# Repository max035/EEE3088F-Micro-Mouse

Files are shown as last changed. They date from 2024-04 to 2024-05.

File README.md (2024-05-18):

# EEE3088F-Micro-Mouse

This project is made up of five modulues. Namely the mother board, the processor, power and sensing. We will be focusing on power and sensing.

## Sensing Subsystem

The sensing subsystem is a crucial component of the micro-mouse project, responsible for detecting walls and enabling the robot to navigate the maze effectively. This subsystem consists of three main components:

1. Emitter-Receiver (ER) Sensor Subsystem
2. Power Saving Mechanism
3. Output and Level Shifting

### Emitter-Receiver (ER) Sensor Subsystem

The ER sensor subsystem includes three separate ER circuits for left, front, and right wall detection. Each circuit utilizes a TSAL4400 IR emitting diode and an SFH203 photodiode. The emitter circuit is designed to provide the optimal current of 100mA to the IR emitting diode, while the receiver circuit uses a 100kΩ resistor in series with the photodiode for sensitive output.

### Power Saving Mechanism

To reduce power consumption, the sensing subsystem employs Pulse Width Modulation (PWM) to control the duty cycle of the ER circuits. PWM allows the ER sensors to operate for a shorter time while still functioning as intended, resulting in significant power savings compared to continuous operation.

### Output and Level Shifting

Initially, the analog output signals from the ER sensors were intended to be converted to digital levels using an NPN and PNP transistor-based level shifter. However, during testing, it was determined that connecting the analog outputs directly to the ADC pins of the microcontroller (PA4, PA5, PA6) provided a more adaptable and robust solution for handling variations in ambient light conditions.

### PCB Design

The sensing subsystem PCB has been designed to fit within the available space on the micro-mouse chassis, with a width less than 70mm and a length between 6mm and 50mm. The PCB includes strategically placed jumpers for debugging and test points for probing, facilitating easy troubleshooting and modification. The PCB connects to the motherboard via a 2x14 pin header.

### Acceptance Testing

The sensing subsystem has undergone rigorous acceptance testing to ensure its functionality, reliability, and compatibility with the micro-mouse platform. The testing procedures covered the following aspects:

1. Functionality test of the ER subsystems (AT-01)
2. Consistency test of the sensing subsystem's output voltage (AT-02)
3. Functionality test of the sensing subsystem software (AT-03)
4. Power consumption test of the sensing subsystem (AT-04)
5. Physical compatibility test (AT-05)

The results of the acceptance tests demonstrated the effectiveness of the design decisions and modifications made throughout the project, ensuring that the sensing subsystem meets the project's requirements and specifications.

For more detailed information on the sensing subsystem design, testing, and results, please refer to the [project report](/Sensing%20Subsystem/Write%20Up/EEE3088F_final_report.pdf).

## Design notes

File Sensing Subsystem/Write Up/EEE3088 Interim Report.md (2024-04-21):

# Introduction

## Problem Description
The micro-mouse project aims to design and construct subassemblies for a simplified maze-solving robot. The project is divided into four modules: processor, motherboard, sensing, and power. Working in pairs, each student is responsible for designing either the sensing or power subsystem. The objective is to create a functional micro-mouse that navigates a maze while adhering to a strict budget and meeting the specified requirements for each subsystem. The sensing subsystem, which is the focus of this report, plays a crucial role in detecting obstacles and walls, enabling the micro-mouse to navigate the maze effectively.

## Scope and limitations
The scope of this project is limited to the design and implementation of the sensing subsystem for the micro-mouse robot. The subsystem will include obstacle detection sensors, power-saving features, and the necessary code to interface with the processor board. However, the design will not cover the integration of the sensing subsystem with the other modules or the overall navigation algorithm for the micro-mouse.

The project's limitations include the strict budget constraints, which may impact component selection and design choices. Additionally, the sensing subsystem's performance may be affected by factors such as sensor accuracy, ambient light conditions, and battery life. Testing and development may also be limited by the availability of resources and time constraints.

# Requirements Analysis

## Requirements

| ID | Requirement |
| ----- | --- |
| UR-01 | The sensing subsystem should detect walls in front and on the sides of the micro-mouse. |
| UR-02 | The sensing subsystem should consume minimal power to maximize battery life. |
| UR-03 | The sensing subsystem should be reliable and consistently detect walls. |
| FR-01 | The sensing subsystem must include sensors capable of detecting walls within a suitable range for maze navigation. |
| FR-02 | The sensing subsystem must use PWM to control the sensor power, reducing overall power consumption. |
| FR-03 | The sensing subsystem must communicate wall detection data to the processor board through the state of the LEDs. |
| FR-04 | The sensing subsystem must fit within the available space on the micro-mouse chassis and connect to the 2x14 pin header on the motherboard. |
| FR-05 | The sensing subsystem must include software that processes sensor data and determines the presence of walls on the left, right, and front of the micro-mouse. |

## Specifications

| ID | Specification |
| --- | --- |
| SPEC-01 | The sensing subsystem shall detect walls within a range suitable for the micro-mouse maze navigation. |
| SPEC-02 | The sensing subsystem shall use a PWM duty cycle that reduces power consumption by at least 50% compared to continuous operation. |
| SPEC-03 | The sensing subsystem shall use the processor board's LEDs to indicate the presence of walls, with one LED each for the left, right, and front walls. |
| SPEC-04 | The sensing subsystem PCB shall fit within the available space on the micro-mouse chassis and connect to the 2x14 pin header on the motherboard. |
| SPEC-05 | The sensing subsystem software shall process sensor data and determine the presence of walls. |

## Testing Procedures

| ID | Test Procedure | Test Method | Pass/Fail Criteria |
| --- | --- | --- | --- |
| TEST-01 | Verify that the sensing subsystem detects walls within the suitable range for maze navigation. | Place the micro-mouse in a controlled environment with walls at various distances and orientations. Monitor the sensor output and LED indicators. | The sensing subsystem should consistently detect walls within the suitable range, and the corresponding LEDs should illuminate. |
| TEST-02 | Verify that the sensing subsystem reduces power consumption by at least 50% using PWM compared to continuous operation. | Measure the sensing subsystem's power consumption with PWM enabled and disabled. Compare the results. | The power consumption with PWM enabled should be at least 50% lower than with PWM disabled. |
| TEST-03 | Verify that the sensing subsystem communicates wall detection data to the processor board through the state of the LEDs. | Place the micro-mouse in a controlled environment with walls on the left, right, and front. Observe the LED indicators. | The corresponding LEDs should illuminate when walls are detected on the left, right, or front of the micro-mouse, effectively communicating the wall detection data to the processor board. |
| TEST-04 | Verify that the sensing subsystem PCB fits within the available space on the micro-mouse chassis and connects to the 2x14 pin header on the motherboard. | Assemble the sensing subsystem PCB onto the micro-mouse chassis and check for proper fit and connection. | The sensing subsystem PCB should fit within the available space without interference and securely connect to the 2x14 pin header. |
| TEST-05 | Verify that the sensing subsystem software processes sensor data and determines the presence of walls on the left, right, and front of the micro-mouse.  | Place the micro-mouse in a controlled environment with walls on the left, right, and front. Monitor the sensor data and wall presence indicators. | The sensing subsystem software should accurately determine the presence of walls based on the sensor data. |

## Traceability Analysis

| FR ID | Specification ID(s) | Testing Procedure ID(s) |
| ----- | --- | --- |
| FR-01 | SPEC-01 | TEST-01 |
| FR-02 | SPEC-02 | TEST-02 |
| FR-03 | SPEC-03 | TEST-03 |
| FR-04 | SPEC-04 | TEST-04 |
| FR-05 | SPEC-05 | TEST-05 |

FR-01 is satisfied by SPEC-01, which states that the sensing subsystem shall detect walls within a range suitable for micro-mouse maze navigation. This requirement is verified by TEST-01, where the micro-mouse is placed in a controlled environment with walls at various distances and orientations to ensure that the sensing subsystem consistently detects walls within the suitable range.

FR-02 is satisfied by SPEC-02, which states that the sensing subsystem shall use a PWM duty cycle that reduces power consumption by at least 50% compared to continuous operation. This requirement is verified by TEST-02, where the power consumption of the sensing subsystem is measured with PWM enabled and disabled, and the results are compared to ensure that the power consumption with PWM enabled is at least 50% lower than with PWM disabled.

FR-03 is satisfied by SPEC-03, which states that the sensing subsystem shall use the processor board's LEDs to indicate the presence of walls, with one LED each for the left, right, and front walls. This requirement is verified by TEST-03, where the micro-mouse is placed in a controlled environment with walls on the left, right, and front, and the LED indicators are observed to ensure that the corresponding LEDs illuminate when walls are detected, effectively communicating the wall detection data to the processor board.

FR-04 is satisfied by SPEC-04, which states that the sensing subsystem PCB shall fit within the available space on the micro-mouse chassis and connect to the 2x14 pin header on the motherboard. This requirement is verified by TEST-04, where the sensing subsystem PCB is assembled onto the micro-mouse chassis and checked for proper fit and connection to ensure that it fits within the available space without interference and securely connects to the 2x14 pin header.

FR-05 is satisfied by SPEC-05, which states that the sensing subsystem software shall process sensor data and determine the presence of walls. This requirement is verified by TEST-05, where the micro-mouse is placed in a controlled environment with walls on the left, right, and front, and the sensor data and wall presence indicators are monitored to ensure that the sensing subsystem software accurately determines the presence of walls based on the sensor data.

# Design Decisions

## Component Selection

### Sensor Types Considered

| Sensor Type | Description | Pros | Cons |
| --- | --- | --- | --- |
| QRD1114 | Reflective object sensor with integrated infrared emitting diode and NPN silicon photodarlington | - Compact all-in-one package<br>- Ideal for non-contact detection of reflective materials<br>- Can detect objects in close proximity or differentiate between black and white surfaces | - Did not work well for long distances<br>- Not used in the breadboard assignment |
| SFH205 + TSAL6100 | Photodiode (SFH205) paired with high-power infrared emitting diode (TSAL6100) | - Proved to work well for longer distances<br>- SFH205 has a short switching time and is suitable for 950 nm wavelength applications<br>- TSAL6100 has a peak wavelength of 940 nm, making it a good match for the SFH205 | - Sensitive to environmental lighting<br>- Potentially higher complexity and cost due to multiple components |

**Selected Sensor: SFH205 + TSAL6100**  
**Reasons:**  
- Better performance at longer distances  
- Prior experience with these components during the breadboard assignment  

## Voltage Regulation and Level Shifting

### Circuit Type Considered

| Circuit Type | Pros | Cons |
| --- | --- | --- |
| Voltage Regulator | - Possibly more stable and reliable<br>- Typically used for stepping down voltages, not suitable for stepping up small, fluctuating voltages<br>- Higher power consumption | - More expensive than transistor-based solutions |
| MOSFET-based Level Shifter | - Less complex than transistor-based solution<br>- More precise | - Less familiarity with MOSFETs<br>- Possibly higher power consumption |
| Transistor-based Level Shifter (NPN + PNP) | - Readily available components<br>- Inexpensive<br>- Simulated and tested, proving to be sufficient for the application | - Slightly more complex than MOSFET-based solution |

**Selected Circuit: Transistor-based Level Shifter (NPN + PNP)**  
**Reasons:**  
- Familiarity with transistors  
- Readily available components in case of damage  
- Cost-effective solution  

## Sensing Subsystem Subcircuits

1. Emitting Circuit
2. Receiver Circuit
3. Level Switching/Shifting Circuit

## Interfacing

- 2x14 connector for interfacing with the main system

# My comment:
Mistakes I made in the EEE3088 Project:
+Used a GPIO pin do drive current into my circuit instead of as battery: A GPIO pin in an STM32 does not supply a lot of current(25mA maximum), it should instead be used as reference(switch). I should have connected the GPIO pin to a MOSFET that is connected to the BATT pin so 
it can drive the circuit instead. This error will result in the insufficient current driving the circuit.
+Insufficient use of Jumpers and test points: Now that I am noticing all the mistakes I have made, having more strategically placed jumpers and test points would have help me on my journey to fix the PCB.
+Small track width: I used a small track width of 0.2mm, this is not advisable for high currents(do research)
+Approach to design: I approached this project from the wrong prospective. I should have built based on available components in JLPCB, Instead,
I build the circuit with components I wanted and them realized that the components were not available/feasible, making me work around my design, downgrading my design, and making compromises late in the design process
that affected the quality of the final product. Instead if I had a scope of available components and worked from there I would have made less design mistakes and compromises.
(The reason I took my initial approach is because I had already built my initial design with everything working(well suited components selected) so I thought it would just be a matter of building from there. 
TLDR: should have designed with component availability in mind earlier on.
+Lack of understanding of components specifications: I should have also designed with the ratings of the components in mind, as in:
The GPIO pin is basically rated at 3V3 25mA, so I would never handed more that 25mA demand, which is a problem because the sensing portion of my circuit requires a current well over 25mA, for instance, the IR emitter
requires like 100mA to emit to far distances
+Going over design. Double checking everything: I made some silly mistakes in this design like forgetting to correctly assign certain important Netlabels making some of my routing incorrect.
A check of Netlabels should be done to ensure everything is going to the right place.
+Willness to go outside my comfort zone: Had I had the courage I would have used unfamiliar components that would clearly benefited me, e.g. MOSFET, different photodiode(components in general) from the one I used in the Breadboard Assignment,
etc...
+For the emitter circuit, instead of using a low resistor value to get the desired current, I would use a npn as a current source to drive it
+I choose to go for a switching circuit where once a certain voltage is reached based on distance, the circuit would indicated that by turning on an led, this would be directly via a level shifter.
+Another way I could have done this is via Analogue to Digital Conversion, where I would have taken the voltage read by the circuit and coded it to determine when the voltage is on instead via ADC. It could have made a better design in 2 ways. 1. Less components used as no need for level shifting circuit. 2. Possibly more precise way to capture signal received by the receiver circuit for use achieving requirement via ADC. It might have also been more precise maybe, I'm not sure.
+Seem it is advisable to use ground plane on the top and bottom of the PCB. I did not do this, it seems to not be too much of a train smash. But maybe the configuration of the ADC would have been a bit complex

+Another circuit I did consider was a transimpedance amplifier for better current to voltage "conversion". But didn't end up doing with it because of the potential expense in power and cost(given the limited budget) of adding an op amp

# My design desisions
## Emitter Reciever Subsystem
### Emitter Circuit
- From the breadboard assignment, the TSAL6100 was perfect component for IR Sensor applications.
- With enough current though, $I_{f}=100mA$ is worked well to reach

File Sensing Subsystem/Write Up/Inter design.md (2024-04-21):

# Chapter 1: Introduction

## 1.1 Problem Description

The micro-mouse project aims to design and construct subassemblies for a simplified maze-solving robot. The project is divided into four modules: processor, motherboard, sensing, and power. Working in pairs, each student is responsible for designing either the sensing or power subsystem. The objective is to create a functional micro-mouse that navigates a maze while adhering to a strict budget and meeting the specified requirements for each subsystem. The sensing subsystem, which is the focus of this report, plays a crucial role in detecting obstacles and walls, enabling the micro-mouse to navigate the maze effectively.

## 1.2 Scope and Limitations

The scope of this project is limited to the design and implementation of the sensing subsystem for the micro-mouse robot. The subsystem will include obstacle detection sensors, power-saving features, and the necessary code to interface with the processor board. The design will cover the integration of the sensing subsystem with the other modules and the overall navigation algorithm for the micro-mouse, which will be discussed in the System Integration and Interfacing section.

The project's limitations include the strict budget constraints, which may impact component selection and design choices. Additionally, the sensing subsystem's performance may be affected by factors such as sensor accuracy, ambient light conditions, and battery life. Testing and development may also be limited by the availability of resources and time constraints.

## 1.3 GitHub Link

https://github.com/username/micromouse-sensing-subsystem

# Chapter 2: Requirements Analysis

## 2.1 Requirements

Table 2.1: User and functional requirements of the sensing subsystem.

| Requirement ID | Description |
| --- | --- |
| UR-01 | The sensing subsystem should detect walls in front and on the sides of the micro-mouse. |
| UR-02 | The sensing subsystem should consume minimal power to maximize battery life. |
| UR-03 | The sensing subsystem should be reliable and consistently detect walls. |
| FR-01 | The sensing subsystem must include sensors capable of detecting walls within a suitable range for maze navigation. |
| FR-02 | The sensing subsystem must use a power-saving mechanism to reduce overall power consumption. |
| FR-03 | The sensing subsystem must communicate wall detection data to the processor board through the state of the LEDs. |
| FR-04 | The sensing subsystem must fit within the available space on the micro-mouse chassis and connect to the 2x14 pin header on the motherboard. |
| FR-05 | The sensing subsystem must include software that processes sensor data and determines the presence of walls on the left, right, and front of the micro-mouse. |

## 2.2 Specifications

Table 2.2: Specifications of the sensing subsystem derived from the requirements in Table 2.1.

| Specification ID | Description |
| --- | --- |
| SPEC-01 | The sensing subsystem shall detect walls within a range suitable for the micro-mouse maze navigation, with a block in the maze being 200mm x 200mm. |
| SPEC-02 | The sensing subsystem shall use a power-saving mechanism that significantly reduces power consumption compared to continuous operation. |
| SPEC-03 | The sensing subsystem shall use the processor board's LEDs to indicate the presence of walls, with one LED each for the left, right, and front walls. |
| SPEC-04 | The sensing subsystem PCB shall fit within the available space on the micro-mouse chassis and connect to the 2x14 pin header on the motherboard. |
| SPEC-05 | The sensing subsystem software shall process sensor data and determine the presence of walls. |

## 2.3 Testing Procedures

Table 2.3: Summary of the testing procedures detailed in Chapter 4.

| Acceptance Test ID | Description |
| --- | --- |
| AT-01 | Verify that the sensing subsystem detects walls within the suitable range for maze navigation. |
| AT-02 | Verify that the sensing subsystem reduces power consumption using a power-saving mechanism compared to continuous operation. |
| AT-03 | Verify that the sensing sub  system communicates wall detection data to the processor board through the state of the LEDs. |
| AT-04 | Verify that the sensing subsystem PCB fits within the available space on the micro-mouse chassis and connects to the 2x14 pin header on the motherboard. |
| AT-05 | Verify that the sensing subsystem software processes sensor data and determines the presence of walls on the left, right, and front of the micro-mouse.  |

## 2.4 Traceability Analysis

Table 2.4: Requirements Traceability Matrix

| # | Requirements | Specifications | Acceptance Test |
| --- | --- | --- | --- |
| 1 | UR-01 | SPEC-01 | AT-01 |
| 2 | UR-02 | SPEC-02 | AT-02 |
| 3 | UR-03 | SPEC-03, SPEC-05 | AT-03, AT-05 |
| 4 | FR-01 | SPEC-01 | AT-01 |
| 5 | FR-02 | SPEC-02 | AT-02 |
| 6 | FR-03 | SPEC-03 | AT-03 |
| 7 | FR-04 | SPEC-04 | AT-04 |
| 8 | FR-05 | SPEC-05 | AT-05 |

### 2.4.1 Traceability Analysis 1

UR-01 is satisfied by SPEC-01, which states that the sensing subsystem shall detect walls within a range suitable for micro-mouse maze navigation, with a block in the maze being 200mm x 200mm. This requirement is verified by AT-01, where the micro-mouse is placed in a controlled environment with walls at various distances and orientations to ensure that the sensing subsystem consistently detects walls within the suitable range.

### 2.4.2 Traceability Analysis 2

UR-02 is satisfied by SPEC-02, which states that the sensing subsystem shall use a power-saving mechanism that significantly reduces power consumption compared to continuous operation. This requirement is verified by AT-02, where the power consumption of the sensing subsystem is measured with the power-saving mechanism enabled and disabled, and the results are compared to ensure that the power consumption with the power-saving mechanism enabled is significantly lower than with it disabled.

### 2.4.3 Traceability Analysis 3

UR-03 is satisfied by SPEC-03 and SPEC-05. SPEC-03 states that the sensing subsystem shall use the processor board's LEDs to indicate the presence of walls, with one LED each for the left, right, and front walls. SPEC-05 states that the sensing subsystem software shall process sensor data and determine the presence of walls. These requirements are verified by AT-03 and AT-05, respectively. AT-03 checks if the corresponding LEDs illuminate when walls are detected, effectively communicating the wall detection data to the processor board. AT-05 verifies that the sensing subsystem software accurately determines the presence of walls based on the sensor data.

### 2.4.4 Traceability Analysis 4

FR-01 is satisfied by SPEC-01, which states that the sensing subsystem shall detect walls within a range suitable for the micro-mouse maze navigation, with a block in the maze being 200mm x 200mm. This requirement is verified by AT-01, where the micro-mouse is placed in a controlled environment with walls at various distances and orientations to ensure that the sensing subsystem consistently detects walls within the suitable range.

### 2.4.5 Traceability Analysis 5

FR-02 is satisfied by SPEC-02, which states that the sensing subsystem shall use a power-saving mechanism that significantly reduces power consumption compared to continuous operation. This requirement is verified by AT-02, where the power consumption of the sensing subsystem is measured with the power-saving mechanism enabled and disabled, and the results are compared to ensure that the power consumption with the power-saving mechanism enabled is significantly lower than with it disabled.

### 2.4.6 Traceability Analysis 6

FR-03 is satisfied by SPEC-03, which states that the sensing subsystem shall use the processor board's LEDs to indicate the presence of walls, with one LED each for the left, right, and front walls. This requirement is verified by AT-03, where the micro-mouse is placed in a controlled environment with walls on the left, right, and front, and the LED indicators are observed to ensure that the corresponding LEDs illuminate when walls are detected, effectively communicating the wall detection data to the processor board.

### 2.4.7 Traceability Analysis 7

FR-04 is satisfied by SPEC-04, which states that the sensing subsystem PCB shall fit within the available space on the micro-mouse chassis and connect to the 2x14 pin header on the motherboard. This requirement is verified by AT-04, where the sensing subsystem PCB is assembled onto the micro-mouse chassis and checked for proper fit and connection to ensure that it fits within the available space without interference and securely connects to the 2x14 pin header.

### 2.4.8 Traceability Analysis 8

FR-05 is satisfied by SPEC-05, which states that the sensing subsystem software shall process sensor data and determine the presence of walls. This requirement is verified by AT-05, where the micro-mouse is placed in a controlled environment with walls on the left, right, and front, and the sensor data and wall presence indicators are monitored to ensure that the sensing subsystem software accurately determines the presence of walls based on the sensor data.

# Chapter 3: Subsystem Design

## 3.1 Design Decisions

### 3.1.1 Final Design

![[Screenshot 2024-04-18 200731.png]]

![[Screenshot 2024-04-17 222953.png]]

![[Screenshot 2024-04-17 223008.png]]

![[Screenshot 2024-04-17 223117.png]]

![[Screenshot 2024-04-17 204755.png]]

---
## 3.1 Design Decisions

### 3.1.1 Component Selection

| Component | Options Considered | Pros | Cons | Final Selection |
| --- | --- | --- | --- | --- |
| IR Emitting Diode | - TSAL6100<br>- TSAL6200<br>- TSAL4400 | - Work well at 100mA current<br>- Suitable for desired sensing distance<br>- Low power consumption <br> - Familiarity with component TSAL6100 due to breadboard assignment | - Limited stock availability on JLCPCB for TSAL6100 and TSAL6200 <br>- TSAL4400 is made to sense IR light from it top, unlike the side body for the TSAL6100 and TSAL6200 | TSAL4400 <br>- Reason: Component availability |
| Photodiode | - SFH205FA<br>- SFH203PFA | - Suitable for side-facing detection<br>- Works well with 100kΩ resistor in reverse bias configuration <br> - Familiarity with component SFH205FA due to breadboard assignment | - Limited stock availability on JLCPCB for SFH205FA <br>- SFH203 is made to sense IR light from it top, unlike the side body for the SFH205 | SFH203PFA <br>- Reason: Component availability |
| Phototransistor | - QRD113<br>- QRD114 | - Suitable for short-distance applications <br>- Good stock availability on JLCPCB | - Not suitable for long-distance sensing required in this project | Not selected <br>- Reason: Component availability |

The TSAL4400 and SFH203PFA were chosen primarily due to their availability on JLCPCB, despite the limitations compared to the TSAL6100 and SFH205FA. The IR emitting diode and photodiode combination was preferred over phototransistors (QRD113 and QRD114) because of their proven performance in long-distance sensing during the breadboard assignment.

### 3.1.2 Power Saving Mechanism

Pulse Width Modulation (PWM) was selected to control the power supplied to the ER sensors, effectively reducing the overall power consumption of the sensing subsystem. This allows the ER sensors to operate for a shorter time while still functioning as intended, as long as the duty cycle is appropriately configured.

However, it is important to note that sourcing current directly from the GPIO pin may not be the best approach. A better solution would be to use a MOSFET switching circuit with PWM as the switch, and the circuit connected to the 3.7V battery for power. This would ensure that the GPIO pin is not overloaded and the ER sensors receive adequate current.

The appropriate duty cycle will be determined during testing when the PCB is received.

### 3.1.3 Output and Level Shifting

The analog output signals from the ER sensors need to be converted into a format that the processor can use to detect the presence of a wall and control an LED indicator. While an ADC could directly convert the analog signals for processing, a level shifting circuit offers a simpler solution. A level shifter translates signals between different voltage or logic levels, allowing the analog voltages from the ER sensors to be converted to digital levels compatible with the processor. This approach simplifies the interfacing between the sensing subsystem and the processor, enabling efficient wall detection and LED control without the need for a complex ADC solution.

| Design Decision | Options Considered | Pros | Cons | Final Selection |
| --- | --- | --- | --- | --- |
| Level Shifting  | 1. NPN and PNP transistor-based level shifter<br>2. MOSFET-based level shifter | 1. Familiarity with transistors<br>- Easily sourced from White Lab if needed<br>- Less expensive than MOSFETs<br>2. No current drawn at the gate from ER sensor output<br>- Requires only one MOSFET | 1. Requires two transistors<br>2. More expensive than transistors | NPN and PNP transistor-based level shifter |

To ensure that the level-shifting circuit would work reliably with the ER sensor outputs, simulations were conducted using LT Spice. The input into the level shifter was varied, confirming that voltages less than 0.7V resulted in approximately 0V output, while voltages greater than 0.7V resulted in approximately 3.3V output. Additionally, the ER sensor's functionality had already been verified during the breadboard assignment.

### 3.1.4 PCB Layout and Routing

| Design Decision | Description | Rationale |
| --- | --- | --- |
| Component Placement | - ER sensors placed to avoid obstruction by wheels<br>- PCB extended forward to accommodate ER sensors | - Ensure unobstructed wall detection on left and right sides<br>- Maintain compact PCB size while allowing proper ER sensor functionality |
| Routing | - Tracks placed and routed for all components<br>- Ground plane not included on top and bottom layers (mistake) | - Ensure proper connectivity between components<br>- (Mistake) Thought tracks and routing would be sufficient without ground planes |

In hindsight, not including a ground plane on both the front and back of the board was a mistake. Ground planes offer several benefits, such as reducing noise and EMI, enhancing power delivery, facilitating improved thermal management, and simplifying routing.

### 3.1.5 Unique Designs 
#### 1. Unique Design Decision 1: Analog to Digital Logic Converter

Instead of sending the analog output signal from the ER sensor directly to the processor for processing by the ADC, a level shifter was implemented to convert the analog signal to digital logic levels. The level shifter acts as an analog to digital logic converter, where voltages less than 0.7V produce a 0V output, and voltages greater than 0.7V produce a 3.3V output. This approach simplifies the interfacing between the sensing subsystem and the processor, as the processor can directly use the digital logic levels for wall detection.

#### 2. Unique Design Decision 2: PCB Shape Modification for Sensor Placement

The provided template for the sensing subsystem PCB design posed a challenge, as the left and right sensors would be obstructed by the wheels of the micromouse. To overcome this issue, the decision was made to extend the PCB forward just enough to ensure that the sensors were not obstructed. This modification required careful consideration to maintain the micromouse's ability to fit within one block of the maze and to minimize the impact on the center of gravity.

An alternative solution considered was to rotate the board to still obtain left and right wall data while avoiding wheel obstruction. However, this approach was deemed potentially more complicated than simply extending the board.

#### 3. Unique Design Decision 3: Jumper for Potentiometer Calibration

A jumper was included in the design to allow for the connection of a potentiometer. The potentiometer can be used to fine-tune the output of the ER sensor if calibration is needed. Although the potentiometer was not populated to reduce costs, it can be easily sourced from the White Lab if required. This design decision provides flexibility in adjusting the sensing subsystem's performance without the need for significant hardware modifications.

---

The final solution for the sensing subsystem consists of three main components:

1. Emitter-Receiver (ER) Sensor Subsystem: Three separate ER circuits for left, front, and right wall detection, each using a TSAL4400 IR emitting diode and an SFH203 photodiode.
2. Power Saving Mechanism: Pulse Width Modulation (PWM) is used to reduce power consumption by controlling the duty cycle of the ER circuits.
3. Output and Level Shifting: An NPN and PNP transistor-based level shifter is used to convert the output signals from the ER circuits to digital levels suitable for the GPIO pins of the STM32 processor.

## 3.2 Failure Management

Table 3.1: Failure management processes and their rationale.

| Failure Management Process | Description | Rationale |
| --- | --- | --- |
| Jumpers for debugging | Jumpers were placed at strategic locations on the PCB. | Jumpers allow for easy debugging and troubleshooting by providing access points to test and isolate different parts of the circuit. They could also be used as a means to place other components onto the PCB if needed. |
| Test points for probing | Test points were included at critical nodes in the circuit. | Test points facilitate probing and measuring signals at various stages of the circuit, aiding in diagnosing issues and verifying correct operation. |
| Potentiometer jumper option | A jumper option was included to allow the connection of a potentiometer in parallel with the 10kΩ resistor. | The potentiometer provides adjustability for fine-tuning the circuit if needed. It was not populated to reduce costs but can be sourced from the White Lab if required. |
| Overcurrent protection | Current-limiting resistors were used in series with the emitter and other sensitive components. | Current-limiting resistors help prevent damage to components due to excessive current, mitigating the risk of component failure. |
| Decoupling capacitors (not implemented) | Decoupling capacitors could have been placed near IC power pins. | Decoupling capacitors suppress high-frequency noise and stabilize the power supply, reducing the risk of erratic behavior or component failure due to power supply issues. This failure management process was later realized as a potential improvement but was not implemented in the current design. |

## 3.3 System Integration and Interfacing

Table 3.2: Interfacing specifications

| Interface | Description | Pinout/Output |
| --- | --- | --- |
| I001 | PWM signal center the processor to control the center ER Subsystem power | - STM32(PE13) to PE13 Pins of ER Subsystem <br> - STM32(GND) to GND Pins of ER Subsystem |
| I002 | PWM signal from the processor to control the left ER sensor power | - STM32(PE15) to PE15 Pins of ER Subsystem <br> - STM32(GND) to GND Pins of ER Subsystem |
| I003 | PWM signal from the processor to control the right ER sensor power | - STM32(PE11) to PE11 Pins of ER Subsystem <br> - STM32(GND) to GND Pins of ER Subsystem |
| I004 | Digital output from the center Level Shifting Subsystem to the processor | - STM32(3V3) to 3V3 Pin of center Level Shifting Subsystem <br> - STM32(PE11) to PE12 Pins of center Level Shifting Subsystem <br> - STM32(GND) to GND Pins of center Level Shifting Subsystem |
| I005 | Digital output from the left Level Shifting Subsystem to the processor | - STM32(3V3) to 3V3 Pin of center Level Shifting Subsystem <br> - STM32(PE14) to PE14 Pins of left Level Shifting Subsystem <br> - STM32(GND) to GND Pins of left Level Shifting Subsystem |
| I006 | Digital output from the right Level Shifting Subsystem to the processor  | - STM32(3V3) to 3V3 Pin of center Level Shifting Subsystem <br> - STM32(PE10) to PE10 Pins of center Level Shifting Subsystem <br> - STM32(GND) to GND Pins of center Level Shifting Subsystem |

# Chapter 4: Acceptance Testing

## 4.1 Tests

Table 4.1: Subsystem acceptance tests

| Test ID | Description | Testing Procedure | Pass/Fail Criteria |
| --- | --- | --- | --- |
| AT-01 | Front ER sensor wall detection | 1. Place the micro-mouse in front of a wall at various distances (e.g., 50mm, 100mm, 200mm). 2. Monitor the digital output voltage of the front ER sensor level shifter using an oscilloscope connected to the test point. 3. Verify the output voltage changes between 0V and 3.3V according to the wall distance. | Pass: The output voltage switches between 0V and 3.3V from the level shifter based on the wall distance, crossing a predefined threshold for wall detection. Fail: The output voltage does not change significantly with wall distance, or the threshold is not crossed. |
| AT-02 | Left ER sensor wall detection  | 1. Place the micro-mouse with a wall on its left side at various distances (e.g., 50mm, 100mm, 200mm). 2. Monitor the digital output voltage of the left ER sensor level shifter using an oscilloscope connected to the test point. 3. Verify the output voltage changes between 0V and 3.3V according to the wall distance. | Pass: The output voltage switches between 0V and 3.3V from the level shifter based on the wall distance, crossing a predefined threshold for wall detection. Fail: The output voltage does not change significantly with wall distance, or the threshold is not crossed. |
| AT-03 | Right ER sensor wall detection | 1. Place the micro-mouse with a wall on its right side at various distances (e.g., 50mm, 100mm, 200mm). 2. Monitor the digital output voltage of the right ER sensor level shifter using an oscilloscope connected to the test point. 3. Verify the output voltage changes between 0V and 3.3V according to the wall distance. | Pass: The output voltage switches between 0V and 3.3V from the level shifter based on the wall distance, crossing a predefined threshold for wall detection. Fail: The output voltage does not change significantly with wall distance, or the threshold is not crossed. |
| AT-04 | PWM power control | 1. Connect an oscilloscope to the PWM input of each ER sensor (front, left, right). 2. Vary the PWM duty cycle using the processor board. 3. Verify that the ER sensors function as intended at different PWM duty cycles. | Pass: The ER sensors function properly at various PWM duty cycles, indicating that the power-saving mechanism is working as expected. Fail: The ER sensors do not function properly at different PWM duty cycles, suggesting issues with the power-saving mechanism. |
| AT-05 | 3.3V power supply stability | 1. Connect a voltage meter to the 3.3V power supply test point. 2. Monitor the voltage level while the micro-mouse is in operation, with all ER sensors active. 3. Verify that the voltage level remains within the acceptable range (e.g., 3.3V ± 5%). | Pass: The 3.3V power supply voltage remains within the acceptable range during operation. Fail: The voltage level deviates significantly from the acceptable range. |
| AT-06 | Level shifting functionality | 1. Connect an oscilloscope to the analog output of each ER sensor (front, left, right) and the corresponding digital output from the level shifter. 2. Place the micro-mouse in a controlled environment with walls at various distances. 3. Verify that the level shifter converts the analog output to the correct digital levels (0V or 3.3V) based on the wall distance. | Pass: The level shifter accurately converts the analog output to digital levels, with 0V representing no wall detected and 3.3V representing a wall detected. Fail: The level shifter does not correctly convert the analog output to digital levels, or the digital levels do not correspond to the presence or absence of a wall. |

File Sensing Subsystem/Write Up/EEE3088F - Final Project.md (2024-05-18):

# EEE3088F Project Report

# Chapter 1
## Introduction

### 1.1 Problem Description

The micro-mouse project aims to design and construct subassemblies for a simplified maze-solving robot. The project is divided into four modules: processor, motherboard, sensing, and power. Working in pairs, each student is responsible for designing either the sensing or power subsystem. The objective is to create a functional micro-mouse that navigates a maze while adhering to a strict budget and meeting the specified requirements for each subsystem. The sensing subsystem, which is the focus of this report, plays a crucial role in detecting obstacles and walls, enabling the micro-mouse to navigate the maze effectively.

### 1.2 Scope and Limitations

The scope of this project is limited to the design and implementation of the sensing subsystem for the micro-mouse robot. The subsystem will be designed to detect obstacles and walls, incorporate power-saving features, and interface with the processor board. The sensing subsystem's design will cover its integration with the other modules. However, the overall navigation algorithm for the micro-mouse is beyond the scope of this project.

The project's limitations include the strict budget constraints, which may impact component selection and design choices. Additionally, the sensing subsystem's performance may be affected by factors such as sensor accuracy, ambient light conditions, and battery life. Testing and development may also be limited by the availability of resources and time constraints.

### 1.3 GitHub Link

[https://github.com/max035/EEE3088F-Micro-Mouse](https://github.com/max035/EEE3088F-Micro-Mouse)

# Chapter 2
## Requirements Analysis

### 2.1 Requirements

| Requirement ID | Description |
| --- | --- |
| R-01 | The sensing subsystem must include sensors capable of detecting walls within a suitable range for maze navigation |
| R-02 | The sensing subsystem must provide reliable and consistent wall detection, mitigating the effects of ambient light on detection accuracy. |
| R-03 | The sensing subsystem must include software that processes the sensor data, indicating the presence of walls on the left, right, and front of the micro-mouse. |
| R-04 | The sensing subsystem must use a power-saving mechanism to reduce overall power consumption. |
| R-05 | The sensing subsystem must fit within the available space on the micro-mouse chassis and connect to the 2x14 pin header on the motherboard. |

## 2.2 Specifications

| Specification ID | Description |
| --- | --- |
| SPEC-01 | The sensing subsystem shall detect walls on the left, right, and front of the micro-mouse, each with a detection range of 100mm to 200mm, conforming to the size of the maze block being 200mm x 200mm. |
| SPEC-02 | The sensing subsystem shall produce a consistent output voltage or voltage range that is minimally affected by environmental factors to ensure reliable wall detection. |
| SPEC-03 | The sensing subsystem shall include software that reads and interprets sensor data sent by the sensors' output to indicate the presence of walls on the left, right, and front of the micro-mouse, by toggling the PB7, PB5, and PB6 LEDs of the microcontroller, respectively. |
| SPEC-04 | The sensing subsystem shall use a power-saving mechanism that reduces power consumption to 50% or lower compared to standard continuous operation. |
| SPEC-05 | The sensing subsystem PCB shall fit within the available space on the micro-mouse chassis, with a width less than 70mm (from one wheel to the next) and a length greater than 6mm to accommodate the 2x14 connector and less than 50mm to ensure the micro-mouse can navigate the maze effectively. |
### 2.3 Testing Procedures 

| Acceptance Test ID | Description |
| --- | --- |
| AT-01 | Verify that the ER subsystems can detect walls within the specified range of 100mm to 200mm. |
| AT-02 | Test the consistency of the sensing subsystem's output voltage under varying environmental conditions using the analog to digital logic converter. |
| AT-03 | Verify that the sensing subsystem software processes sensor data and indicates the presence of walls by toggling the corresponding LEDs on the microcontroller. |
| AT-04 | Test the power consumption of the sensing subsystem to verify that the PWM power-saving mechanism reduces power consumption by 50% or more compared to continuous operation. |
| AT-05 | Ensure that the sensing subsystem PCB fits within the specified dimensions and connects properly to the 2x14 pin header on the motherboard. |

### 2.4 Traceability Analysis - I'm coming back, Do Acceptance Testing table first

### 2.4 Traceability Analysis

| # | Requirements | Specifications | Acceptance Test |
| --- | --- | --- | --- |
| 1 | R-01 | SPEC-01 | AT-01 |
| 2 | R-02 | SPEC-02 | AT-02 |
| 3 | R-03 | SPEC-03 | AT-03 |
| 4 | R-04 | SPEC-04 | AT-04 |
| 5 | R-05 | SPEC-05 | AT-05 |

#### Traceability Analysis 1
R-01 is satisfied by SPEC-01, which states that the sensing subsystem shall detect walls on the left, right, and front of the micro-mouse, each with a detection range of 100mm to 200mm, conforming to the size of the maze block being 200mm x 200mm. This requirement is verified by AT-01, where the ER subsystems are tested to ensure they can detect walls within the specified range.

#### Traceability Analysis 2
R-02 is satisfied by SPEC-02, which states that the sensing subsystem shall produce a consistent output voltage or voltage range that is minimally affected by environmental factors to ensure reliable wall detection. This requirement is verified by AT-02, which tests the consistency of the sensing subsystem's output voltage under varying environmental conditions using the analog to digital logic converter.

#### Traceability Analysis 3
R-03 is satisfied by SPEC-03, which states that the sensing subsystem shall include software that reads and interprets sensor data sent by the sensors' output to indicate the presence of walls on the left, right, and front of the micro-mouse, by toggling the PB7, PB5, and PB6 LEDs of the microcontroller, respectively. This requirement is verified by AT-03, which checks that the sensing subsystem software processes sensor data and indicates the presence of walls by toggling the corresponding LEDs on the microcontroller.

#### Traceability Analysis 4
R-04 is satisfied by SPEC-04, which states that the sensing subsystem shall use a power-saving mechanism that reduces power consumption to 50% or lower compared to standard continuous operation. This requirement is verified by AT-04, which tests the power consumption of the sensing subsystem to verify that the PWM power-saving mechanism reduces power consumption by 50% or more compared to continuous operation.

#### Traceability Analysis 5
R-05 is satisfied by SPEC-05, which states that the sensing subsystem PCB shall fit within the available space on the micro-mouse chassis, with a width less than 70mm (from one wheel to the next) and a length greater than 6mm to accommodate the 2x14 connector and less than 50mm to ensure the micro-mouse can navigate the maze effectively. This requirement is verified by AT-05, which ensures that the sensing subsystem PCB fits within the specified dimensions and connects properly to the 2x14 pin header on the motherboard.

# Chapter 3
## Subsystem Design

### 3.1 Design Decisions

The design decisions for the sensing subsystem were made based on careful consideration of component options, power-saving mechanisms, output and level shifting, and PCB layout and routing.

#### 3.1.1 Component Selection

| Component | Options Considered | Pros | Cons | Final Selection |
| --- | --- | --- | --- | --- |
| IR Emitting Diode(for Emitting Circuit) | - TSAL6100<br>- TSAL6200<br>- TSAL4400 | - All work well at 100mA current, consuming less power<br>- All suitable for desired sensing distance (noted during breadboard assignment with TSAL6100)<br>- Familiarity with TSAL6100 due to breadboard assignment | - Limited stock availability on JLCPCB for TSAL6100 and TSAL6200<br>- TSAL4400 is designed to sense IR light from its top, unlike the side body for TSAL6100 and TSAL6200 | TSAL4400 - Reason: Component availability |
| Photodiode(for Receiving Circuit) | - SFH205FA<br>- SFH203PFA | - Suitable for side-facing detection<br>- Both work well (producing a sensitive output to reflected IR light) with 100kΩ resistor in reverse bias configuration<br>- Familiarity with SFH205FA due to breadboard assignment | - Limited stock availability on JLCPCB for SFH205FA<br>- SFH203PFA is designed to sense IR light from its top, unlike the side body for SFH205FA | SFH203PFA - Reason: Component availability |
| Phototransistor (Emitter Receiver circuit) | - QRD113<br>- QRD114 | - Suitable for short-distance applications (noted during breadboard assignment)<br>- Good stock availability on JLCPCB | - Not suitable for long-distance sensing required in this project | Not selected - Reason: Component availability and inability to meet project specification of measuring distance |
Due to limited stock availability on JLCPCB, the TSAL4400 and SFH203PFA were used instead of the initially selected TSAL6100 and SFH205FA. This change in component selection was made later in the project, and as a result, the calculations and assumptions throughout the report are based on the TSAL6100 and SFH205FA. This oversight in considering component availability from the beginning was a critical mistake in the approach and has been noted. However, since the TSAL4400 and SFH203PFA belong to the same component family as the initially selected components, they are functionally similar enough to ensure the project's success.

Ultimately, the IR emitting diode and photodiode (emitter-receiver) combination was preferred over phototransistors (QRD113 and QRD114) due to their demonstrated performance in long-distance sensing during the breadboard assignment.

##### Calculations

**Emitter Circuit Calculations** 
From the datasheet for the TSAL6100, we see:
- Voltage drop, $V_{f} = 1.5V$
- Typical current of the emitting diode is 100mA

For the emitter to function properly, it needs to be in series with a resistor that will provide its optimal current of 100mA. $$V_{in} - V_{f} - IR = 0$$ $$V_{in} - V_{f} = IR$$ $$R = \frac{V_{in} - V_{f}}{I} = \frac{3.3 - 1.5}{100mA} = 18\Omega$$

**Receiver Circuit Calculations** The resistor value for the receiver cannot be calculated directly but was determined experimentally during the breadboard assignment. With the photodiode functioning in reverse bias, using very large resistor values produced an output voltage large and sensitive enough for use.

- A $10k\Omega$ resistor produced outputs in the 100s millivolt region (no obstacle), and as the obstacle approached, the output would only increase significantly to around 3V.
- A $100k\Omega$ resistor produced outputs above 1V with no obstacle, and as the obstacle came closer, there was a gradual and clear voltage increase to 3.3V.

Therefore, the resistor used in series with the SFH205FA photodiode will be a $100k\Omega$ resistor.
#### Unique Designs

##### Unique Design Decision 1: Analog to Digital Logic Converter

After obtaining the analog output signal from the emitter-receiver (ER) sensor, the next step was to process and interpret this data for wall detection. One approach to this problem is to send the analog signal directly to the processor for processing using an Analog-to-Digital Converter (ADC). However, implementing an ADC system can be complex and resource-intensive, requiring additional software development and processing power.

To simplify the interfacing between the sensing subsystem and the processor, an alternative approach was chosen. Instead of using an ADC, a level shifter was implemented to convert the analog signal to digital logic levels. The level shifter acts as an analog to digital logic converter, where voltages less than 0.7V produce a 0V output, and voltages greater than 0.7V produce a 3.3V output.

This design decision offers several advantages:

1. Simplified interfacing: The processor can directly use the digital logic levels for wall detection, eliminating the need for complex ADC implementation and signal processing.

2. Reduced software complexity: By avoiding the ADC system, the software development effort is reduced, as the processor can directly interpret the digital logic levels for wall detection.

3. Resource optimization: The level shifter approach conserves processing power and memory resources that would otherwise be required for ADC signal processing, allowing for a more efficient use of the available resources.

By employing a level shifter as an analog to digital logic converter, the sensing subsystem can effectively provide wall detection information to the processor in a simplified and resource-efficient manner. This design decision streamlines the integration of the sensing subsystem with the processor, contributing to the overall functionality and performance of the micro-mouse.

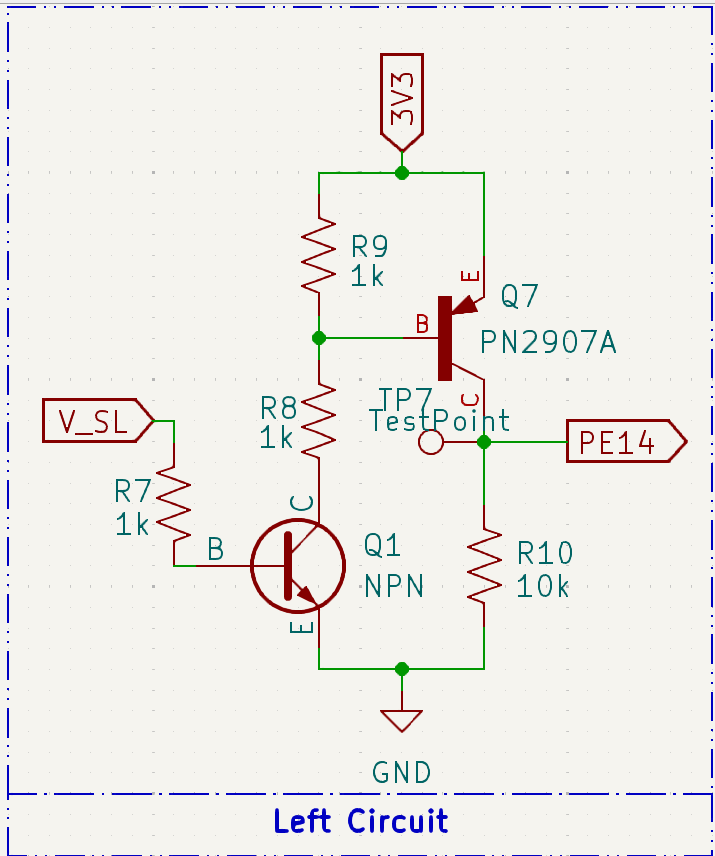
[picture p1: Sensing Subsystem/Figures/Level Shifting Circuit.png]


##### Unique Design Decision 2: PCB Shape Modification for Sensor Placement

The provided template for the sensing subsystem PCB design posed a challenge, as the left and right sensors would be obstructed by the wheels of the micromouse. To overcome this issue, the decision was made to extend the PCB forward just enough to ensure that the sensors were not obstructed. This modification was necessary to prevent the sensors from being blocked by the wheels of the micromouse, which would hinder their ability to detect walls effectively. The extension was carefully designed to maintain the micromouse's ability to fit within one block of the maze and to minimize the impact on the centre of gravity.

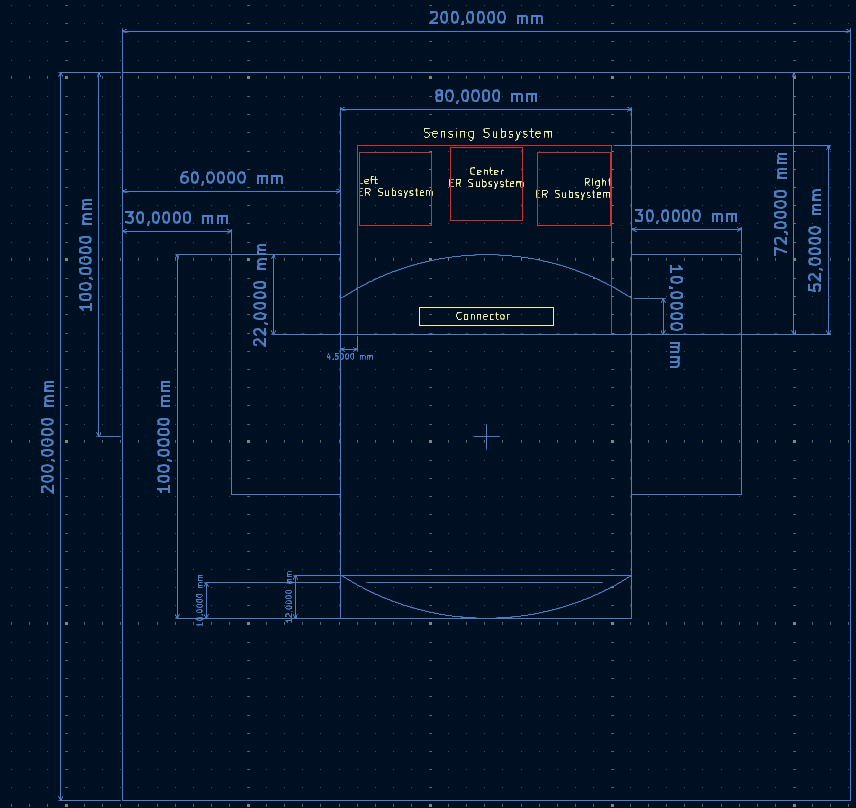
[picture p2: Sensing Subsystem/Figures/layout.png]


An alternative solution considered was to rotate the sensors themselves, rather than modifying the PCB shape, to achieve the desired sensing angles while avoiding wheel obstruction. However, this approach was deemed potentially more complicated than simply extending the board, for several reasons:

1. Rotating the sensors would have required additional mechanical fixtures to secure them at the desired angles, increasing the complexity of the assembly process.

2. The rotated sensors might not have provided reliable sensory data from the sides of the micro-mouse, as the wheels could still obstruct the sensors' field of view.

3. Processing the sensory data from the rotated sensors would have necessitated the use of an Analog-to-Digital Converter (ADC) to interpret the signals and determine the presence of walls on the left and right sides of the micro-mouse. This approach would have significantly increased the complexity of the sensing subsystem, requiring additional software development and signal processing.

By extending the PCB forward, the sensors can be placed in front of the wheels without the need for rotation, ensuring unobstructed detection of walls on the left, right, and front of the micro-mouse. This design choice simplifies the assembly process, enhances the reliability of the sensory data, and eliminates the need for complex signal processing using an ADC.

The modified PCB shape not only accommodates the sensor placement but also optimizes the overall functionality and efficiency of the sensing subsystem, contributing to the successful navigation of the micro-mouse through the maze.

##### Unique Design Decision 3: Jumper for Potentiometer Calibration

In the sensing subsystem, the emitter-receiver (ER) sensor's output can be affected by various factors such as ambient light, sensor tolerance, and surface reflectivity. These factors can lead to variations in the analog output signal, potentially impacting the performance of the level shifter and the overall wall detection accuracy. To address this issue, calibration of the ER sensor's output may be necessary to ensure optimal performance.

To facilitate calibration, a jumper was included in the design to allow for the connection of a potentiometer. The potentiometer can be used to fine-tune the output of the ER sensor, enabling the level shifter to work effectively by providing a means to adjust the sensor output. This decision was made to offer flexibility in calibrating the sensing subsystem without requiring significant hardware modifications.

Although the potentiometer was not populated initially to reduce costs, it can be easily sourced from the White Lab if required. The jumper provides a convenient way to connect the potentiometer when calibration is needed, allowing for quick and easy adjustments to the ER sensor's output.

An alternative approach considered was to place jumpers to the resistors and use them for voltage division fine-tuning. However, this would have been more work than simply placing a potentiometer, as it would require managing multiple jumper configurations and calculating the appropriate resistor values for each calibration setting.

The jumper and potentiometer solution was chosen as it offers several advantages:

1. Flexibility: The potentiometer allows for continuous and precise adjustment of the ER sensor's output, enabling fine-tuning of the calibration to achieve optimal performance.

2. Simplicity: The jumper provides a straightforward means to connect the potentiometer when needed, without requiring complex hardware modifications or jumper configurations.

3. Cost-effectiveness: By not populating the potentiometer initially, the cost of the sensing subsystem is reduced, while still providing the option for calibration if necessary.

By incorporating a jumper for potentiometer calibration, the sensing subsystem gains the ability to adapt to varying environmental conditions and sensor characteristics, ensuring reliable wall detection performance. This design decision demonstrates a balance between flexibility, simplicity, and cost-effectiveness in addressing the potential need for calibration in the sensing subsystem.
#### Final Design

##### Power Saving Mechanism

Pulse Width Modulation (PWM) was selected to control the power supplied to the ER sensors, effectively reducing the overall power consumption of the sensing subsystem. This allows the ER sensors to operate for a shorter time while still functioning as intended, as long as the duty cycle is appropriately configured.

However, it is important to note that sourcing current directly from the GPIO pin may not be the best approach. A better solution would be to use a MOSFET switching circuit with PWM as the switch, and the circuit connected to the 3.7V battery for power. This would ensure that the GPIO pin is not overloaded, and the ER sensors receive adequate current.

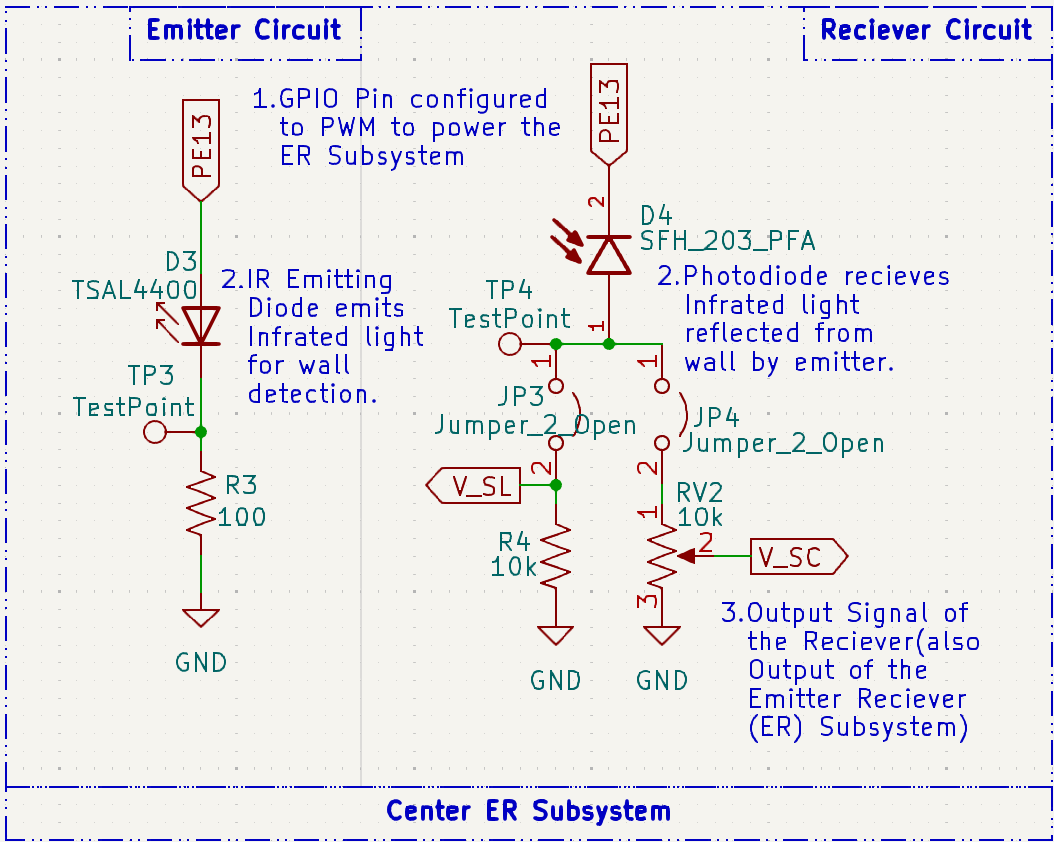
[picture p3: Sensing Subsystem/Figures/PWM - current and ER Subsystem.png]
Current Implementation of PWM (without MOSFET Switching)


![[PWM - Improved (2).png]]
The appropriate duty cycle will be determined during testing when the PCB is received.

##### Output and Level Shifting

The analog output signals from the ER sensors need to be converted into a format that the processor could use to detect the presence of a wall and control an LED indicator. While an ADC could directly convert the analog signals for processing, a level shifting circuit offered a simpler solution. A level shifter translates signals between different voltage or logic levels, allowing the analog voltages from the ER sensors to be converted to digital levels compatible with the processor. This approach simplifies the interfacing between the sensing subsystem and the processor, enabling efficient wall detection and LED control without the need for a complex ADC solution.

| Design Decision | Options Considered | Pros | Cons | Final Selection |
| --- | --- | --- | --- | --- |
| Level Shifting  | - NPN and PNP transistor-based level shifter<br>- MOSFET-based level shifter | - Familiarity with transistors for transistor-based option<br>- Transistors are easily sourced from White Lab if needed<br>- Transistors are less expensive than MOSFETs <br>- No current drawn at the gate from ER sensor output (for MOSFET) | - Requires two transistors (for NPN and PNP)<br>- More expensive than transistors (for MOSFET) | NPN and PNP transistor-based level shifter <br> Reasoning: <br> Component familiarity and availability |

To ensure that the level-shifting circuit would work reliably with the ER sensor outputs, simulations were conducted using LT Spice. The input into the level shifter was varied, confirming that voltages less than 0.7V resulted in approximately 0V output, while voltages greater than 0.7V resulted in approximately 3.3V output. Additionally, the ER sensor's functionality had already been verified during the breadboard assignment.

##### PCB Layout and Routing

| Design Decision | Description | Rationale |
| --- | --- | --- |
| Component Placement | - ER sensors placed to avoid obstruction by wheels<br>- PCB extended forward to accommodate ER sensors | - Ensure unobstructed wall detection on left and right sides<br>- Maintain compact PCB size while allowing proper ER sensor functionality |
| Routing | - Tracks (of width 0.2mm) placed and routed for all components<br>- Ground plane not included on top and bottom layers (mistake) | - Ensure proper connectivity between components, and able to handle current up to 1.4A if needed<br>- (Mistake) Assumed tracks and routing would be sufficient without ground planes |

In hindsight, not including a ground plane on both the front and back of the board was a mistake. Ground planes offer several benefits, such as reducing noise and EMI, enhancing power delivery, facilitating improved thermal management, and simplifying routing.

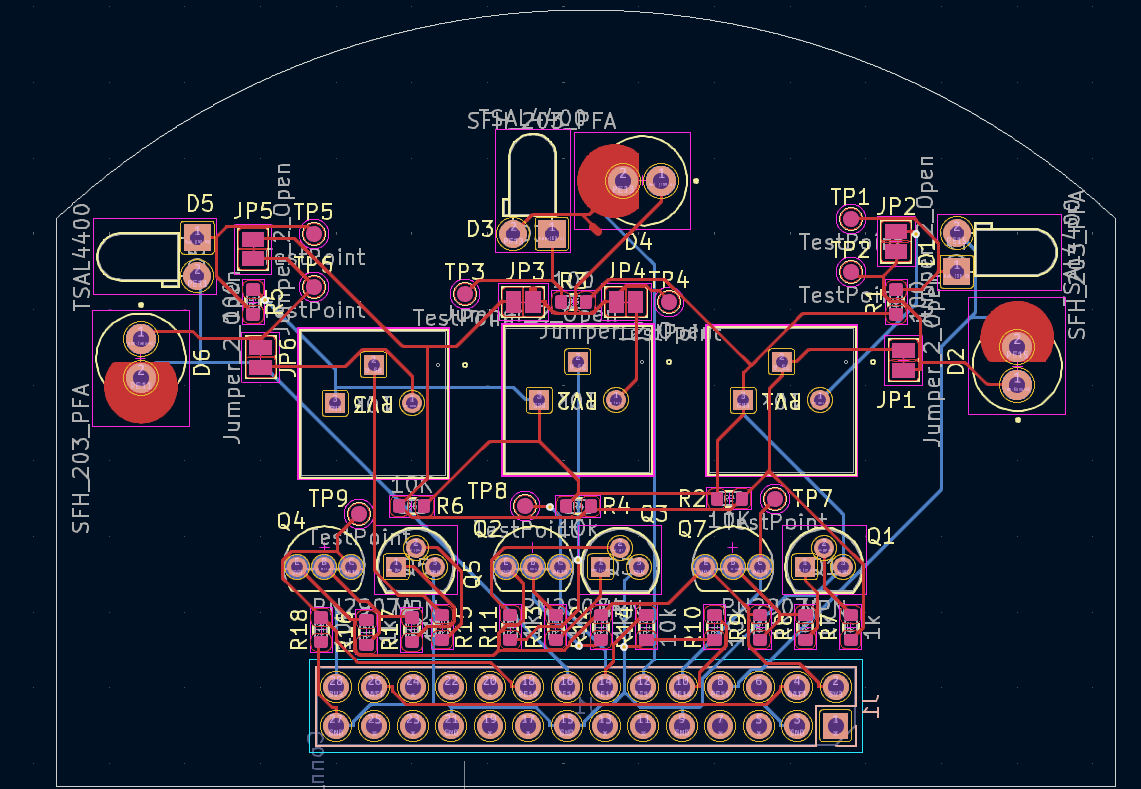
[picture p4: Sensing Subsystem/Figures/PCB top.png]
Current Implementation of PCB layout (without ground planes)


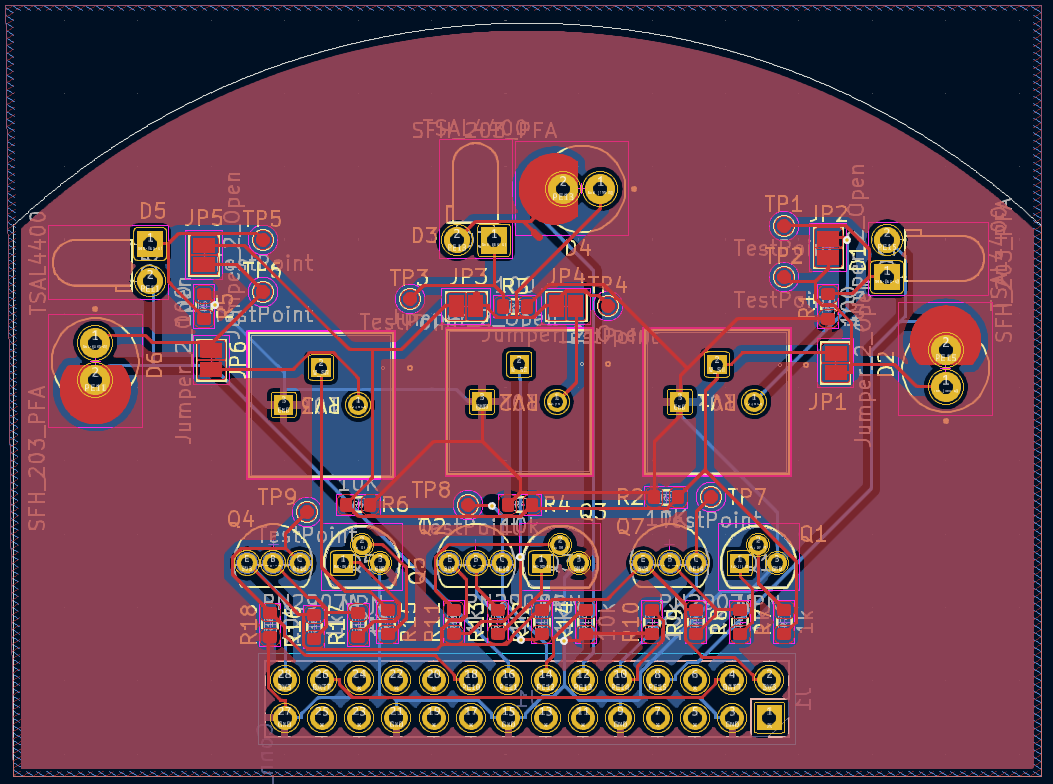
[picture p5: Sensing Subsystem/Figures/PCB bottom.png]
Better implementation of PCB layout (with ground planes)


##### Final solution

The final solution for the sensing subsystem consists of three main components:

1. Emitter-Receiver (ER) Sensor Subsystem: Three separate ER circuits for left, front, and right wall detection, each using a TSAL4400 IR emitting diode and an SFH203 photodiode.
2. Power Saving Mechanism: Pulse Width Modulation (PWM) is used to reduce power consumption by controlling the duty cycle of the ER circuits.
3. Output and Level Shifting: An NPN and PNP transistor-based level shifter is used to convert the output signals from the ER circuits to digital levels suitable for the GPIO pins of the STM32 processor.

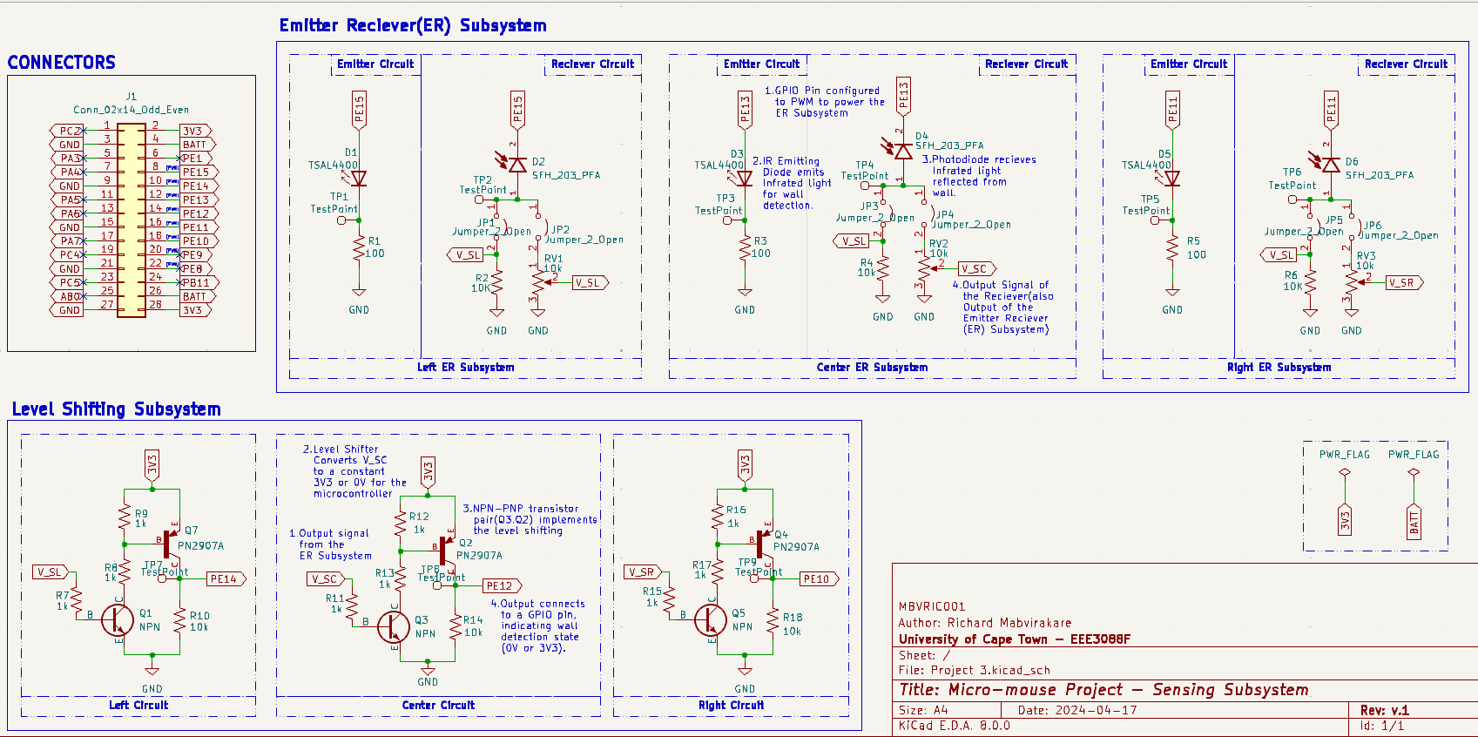
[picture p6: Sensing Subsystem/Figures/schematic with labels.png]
Schematic


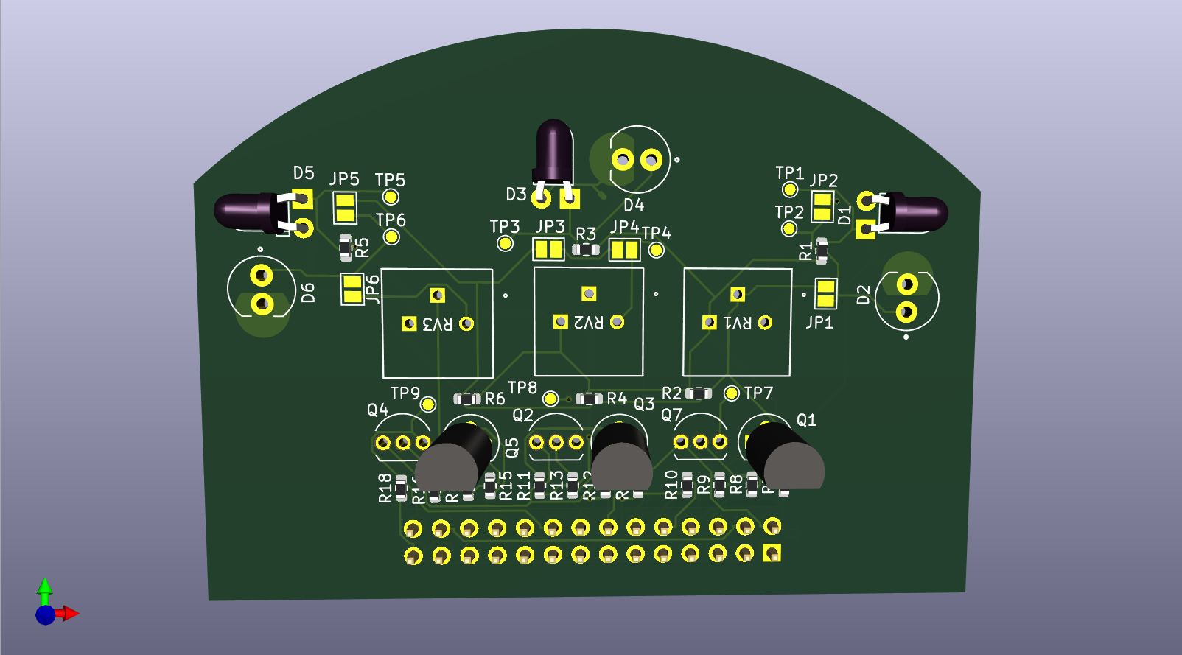
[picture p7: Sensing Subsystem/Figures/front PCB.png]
PCB Front


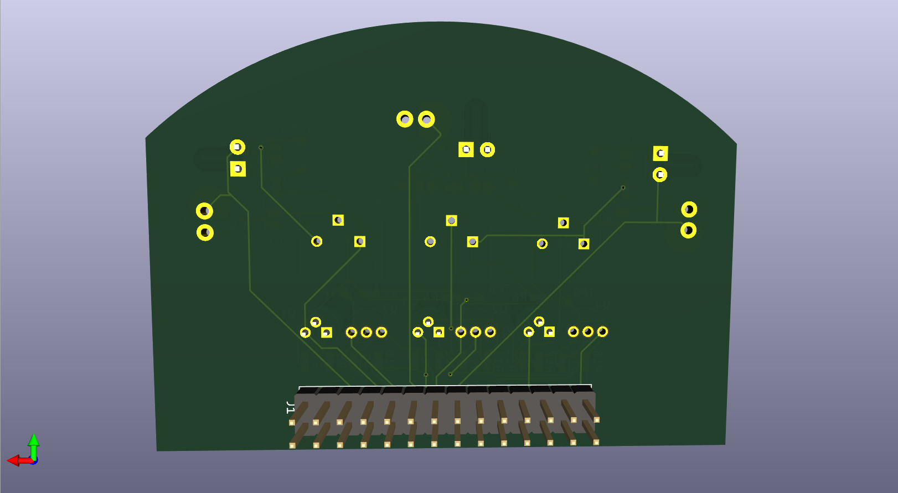
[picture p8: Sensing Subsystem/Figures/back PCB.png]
PCB Back


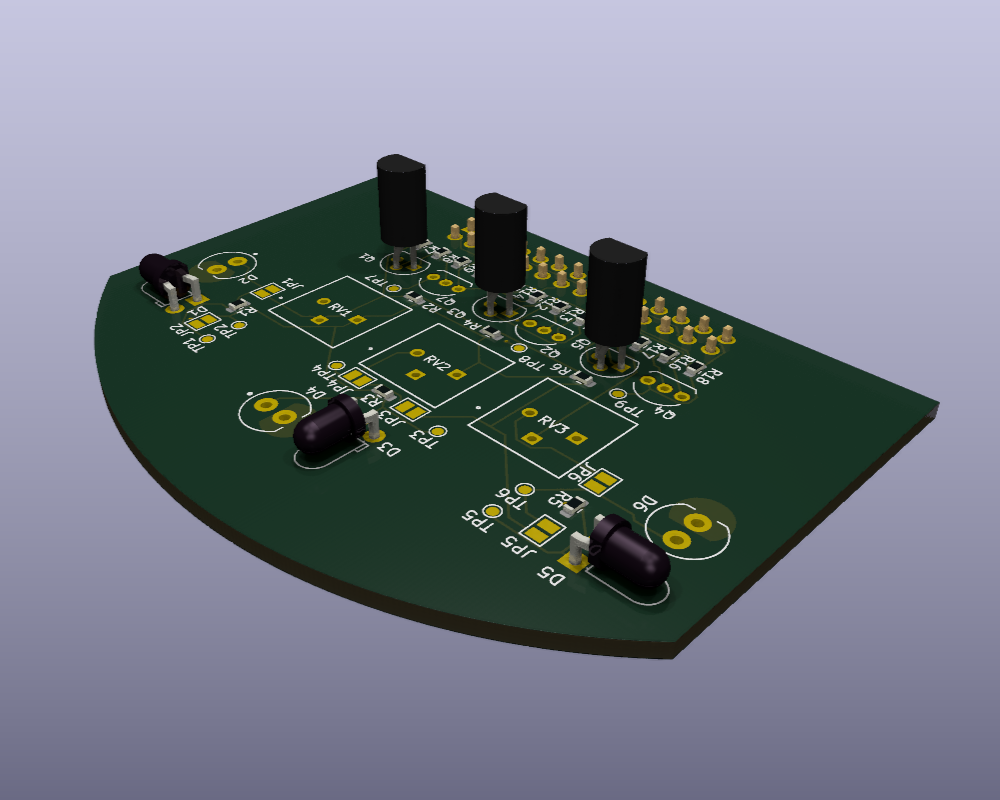
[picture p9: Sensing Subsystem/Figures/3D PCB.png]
PCB 3D


### Failure Management

| Failure Management Process  | Description | Rationale |
| --- | --- | --- |
| Jumpers for debugging | Jumpers were placed at strategic locations on the PCB. | - Jumpers allow for easy debugging and troubleshooting by providing access points to test and isolate different parts of the circuit.<br>- They could also be used as a means to place other components onto the PCB if needed. |
| Test points for probing | Test points were included at critical nodes in the circuit. | - Test points facilitate probing and measuring signals at various stages of the circuit, aiding in diagnosing issues and verifying correct operation. |
| Potentiometer jumper option | A jumper option was included to allow the connection of a potentiometer in parallel with the 10kΩ resistor. | - The potentiometer provides adjustability for fine-tuning the circuit if needed.<br>- It was not populated to reduce costs but can be sourced from the White Lab if required. |

### System Integration and Interfacing

| Interface | Description | Pinout/Output |
| --- | --- | --- |
| I001 | PWM signal from the processor to control the center ER Subsystem power | - STM32(PE13) to Pin 12 (on the 2x14 Connector) of the Sensing Subsystem<br>- STM32(GND) to GND Pin (on the 2x14 Connector) of the Sensing Subsystem |
| I002 | PWM signal from the processor to control the left ER sensor power | - STM32(PE15) to Pin 8 (on the 2x14 Connector) of the Sensing Subsystem<br>- STM32(GND) to GND Pin (on the 2x14 Connector) of the Sensing Subsystem |
| I003 | PWM signal from the processor to control the right ER sensor power | - STM32(PE11) to Pin 16 (on the 2x14 Connector) of the Sensing Subsystem<br>- STM32(GND) to GND Pin (on the 2x14 Connector) of the Sensing Subsystem |
| I004 | Digital output from the center Level Shifting Subsystem to the processor | - STM32(3V3) to 3V3 Pin (on the 2x14 Connector) of the Sensing Subsystem<br>- STM32(PE11) to Pin 14 (on the 2x14 Connector) of the Sensing Subsystem<br>- STM32(GND) to GND Pins (on the 2x14 Connector) of the Sensing Subsystem |
| I005 | Digital output from the left Level Shifting Subsystem to the processor | - STM32(3V3) to 3V3 Pin (on the 2x14 Connector) of the Sensing Subsystem<br>- STM32(PE14) to to Pin 10 (on the 2x14 Connector) of the Sensing Subsystem<br>- STM32(GND) to GND Pin (on the 2x14 Connector) of the Sensing Subsystem |
| I006 | Digital output from the right Level Shifting Subsystem to the processor  | - STM32(3V3) to 3V3 Pin (on the 2x14 Connector) of the Sensing Subsystem<br>- STM32(PE10) to to Pin 18 (on the 2x14 Connector) of the Sensing Subsystem<br>- STM32(GND) to GND Pin (on the 2x14 Connector) of the Sensing Subsystem |
Note:
- Any one of the following pins on the 2x14 Connector of the Sensing Subsystem can be used as ground: Pin 3, Pin 9, Pin 15, Pin 21, or Pin 27. Only one GND pin needs to be connected.
- Any one of the following pins on the 2x14 Connector of the Sensing Subsystem can be used as a 3V3 supply: Pin 2 or Pin 28. Only one 3V3 pin needs to be connected.

![[Untitled Diagram.drawio (1).png]]

## Acceptance Testing

### Tests

| Test ID | Description | Testing Procedure | Pass/Fail Criteria |
| --- | --- | --- | --- |
| AT-01 | Functionality test of the ER subsystems to verify that the sensors can detect walls within the specified range of 100mm to 200mm. This test ensures that the sensing subsystem meets the detection range requirements. | 1. Visually inspect the PCB for any manufacturing defects, poor soldering,  or damaged components (a general inspection).<br>2. Power on the sensing subsystem and verify that the IR emitters are functioning by viewing them through a camera or smartphone camera. The IR light should be visible on the camera display.<br>3. Set up the micro-mouse in a controlled environment with adjustable walls.<br>4. Place a wall at distances of 100mm, 150mm, and 200mm from each sensor (front, left, and right) and verify that the sensor detects its presence by observing a significant change in the output voltage at the corresponding test points (TP4, TP2, and TP6, respectively) compared to the no-obstacle condition. | Pass: The PCB passes visual inspection, the IR emitters function correctly, and all ER subsystems detect the presence of walls at distances of 100mm, 150mm, and 200mm, as indicated by a significant change in output voltage at the corresponding test points compared to the no-obstacle condition.<br>Fail: The PCB fails visual inspection, the IR emitters do not function, or one or more ER subsystems fail to detect the presence of walls at any of the specified distances, with no significant change in output voltage compared to the no-obstacle condition. |
| AT-02 | Consistency test of the sensing subsystem's output voltage under varying environmental conditions (e.g., ambient light levels) using the analog to digital logic converter. This test verifies that the level shifter provides a consistent digital output (0V or 3.3V) based on the analog input, ensuring reliable wall detection minimally affected by environmental factors. | 1. Set up the micro-mouse in a controlled environment with a wall at a fixed distance (e.g., 150mm) from the front sensor.<br>2. Measure the analog output voltage at TP4 and the digital output voltage at TP8 under normal ambient light conditions.<br>3. Verify that the level shifter output at TP8 is approximately 3.3V when the analog voltage is above 0.7V and 0V when the analog voltage is below 0.7V.<br>4. Vary the ambient light intensity (e.g., using a desk lamp or dimming the room lights) and repeat steps 2-3, ensuring that the level shifter output remains consistent.<br>5. Repeat steps 2-4 for the left and right sensors, measuring the analog output voltage at TP2 and TP6, and the digital output voltage at TP7 and TP9, respectively. | Pass: The level shifters consistently provide the correct digital output (0V or 3.3V) based on the analog input from the ER subsystems, ensuring reliable wall detection minimally affected by environmental factors.<br>Fail: The level shifters fail to provide consistent digital outputs based on the analog input from the ER subsystems, or the digital outputs vary significantly with changes in ambient light levels, indicating unreliable wall detection. |
| AT-03 | Functionality test of the sensing subsystem software to verify that it processes sensor data and indicates the presence of walls by toggling the corresponding LEDs (PB7, PB5, PB6) on the microcontroller. This test ensures that the software correctly interprets sensor data and communicates wall detection information. | 1. Set up the micro-mouse in a controlled environment with removable walls on the left, right, and front sides.<br>2. Place a wall on the left side of the micro-mouse and verify that PB7 LED toggles on.<br>3. Remove the left wall and verify that PB7 LED toggles off.<br>4. Repeat steps 2-3 for the right side wall and PB5 LED.<br>5. Repeat steps 2-3 for the front wall and PB6 LED. | Pass: The LEDs (PB7, PB5, PB6) toggle correctly, indicating the presence or absence of walls on the left, right, and front sides, respectively.<br>Fail: One or more LEDs fail to toggle correctly based on the presence or absence of walls, indicating an issue with the sensing subsystem software. |
| AT-04 | Power consumption test of the sensing subsystem to verify that the PWM power-saving mechanism reduces power consumption by 50% or more compared to continuous operation. This test ensures that the sensing subsystem meets the power efficiency requirements. | 1. Measure the current consumption of the sensing subsystem during continuous operation (100% duty cycle) using an ammeter.<br>2. Set the PWM duty cycle to 50% and measure the current consumption again.<br>3. Calculate the percentage reduction in power consumption.<br>4. Repeat steps 2-3 for duty cycles of 25% and 10%.<br>5. Verify that the sensing subsystem still functions correctly at the reduced duty cycles by performing a basic wall detection test. | Pass: The PWM power-saving mechanism reduces the current consumption of the sensing subsystem by 50% or more compared to continuous operation, and the sensing subsystem remains functional at the reduced duty cycles.<br>Fail: The PWM power-saving mechanism fails to reduce the current consumption by at least 50%, or the sensing subsystem does not function correctly at the reduced duty cycles. |
| AT-05 | Physical compatibility test to ensure that the sensing subsystem PCB fits within the specified dimensions (width < 70mm, 6mm < length < 50mm) and connects properly to the 2x14 pin header on the motherboard. This test verifies that the sensing subsystem meets the size and connectivity requirements. | 1. Measure the width of the sensing subsystem PCB at its widest point using a ruler or caliper.<br>2. Measure the length of the sensing subsystem PCB from the edge of the 2x14 pin header to the opposite end.<br>3. Verify that the width is less than 70mm and the length is between 6mm and 50mm.<br>4. Connect the sensing subsystem PCB to the 2x14 pin header on the motherboard, ensuring that all pins are properly aligned.<br>5. Gently tug on the sensing subsystem PCB to confirm that it is securely connected to the motherboard. | Pass: The sensing subsystem PCB has a width less than 70mm, a length between 6mm and 50mm, and connects securely to the 2x14 pin header on the motherboard.<br>Fail: The sensing subsystem PCB exceeds the specified dimensions or does not connect properly to the 2x14 pin header on the motherboard. |
### Critical Analysis of Testing

#### AT-01: Functionality test of the ER subsystems
During the initial testing of the ER subsystems (AT-01), several issues were discovered that significantly impacted the system's performance. Firstly, incorrect resistor values were used for the emitter circuits (R1, R3, R5) and the receiver circuits (R2, R4, R6). The emitter circuits used 100Ω resistors instead of the calculated 18Ω value, while the receiver circuits used 10kΩ resistors instead of the intended 100kΩ. These incorrect values led to suboptimal current flow and signal reception.

Additionally, it was found that powering the ER subsystems directly from the GPIO pins was not a viable solution, as the STM32 datasheet specifies a maximum current of 25mA per pin, which is insufficient for the required 100mA current for the IR emitters. To address this issue, the connections to the GPIO pins (PE15, PE13, PE11) were severed, and the ER subsystems were connected to the 3.7V battery (BATT) via pins 4 and 26 on the 2x14 connector.

During testing, it was observed that the IR emitters produced a faint light, which was attributed to the use of the TSAL4400 model instead of the TSAL6100 used in the breadboard assignment. Furthermore, no definitive output was observed at test points TP4, TP2, and TP6 when varying the distance of an object from the sensors. Upon further investigation, it was discovered that the selected photodiode (SFH203PFA) had an upward sensing direction, which was not suitable for the intended side-sensing application.

To rectify these issues, all SFH203PFA photodiodes were replaced with the side-sensing SFH205FA model, and all TSAL4400 emitters were replaced with the brighter TSAL6100 model, both sourced from the White Lab. After these component replacements, the test was repeated, and the desired outputs were obtained: approximately 1.2V with no obstacle, 1.4V at 200mm, 1.7V at 150mm, and 2.2V at 100mm for all test points (TP4, TP2, TP6).

The successful passing of AT-01 after these modifications highlights the importance of using the correct component values and models, as well as ensuring proper power supply and sensing direction for optimal performance of the ER subsystems.

#### AT-02: Consistency test of the sensing subsystem's output voltage
During the consistency test of the sensing subsystem's output voltage (AT-02), it was observed that the analog output voltages from the ER subsystems were consistently above 1V, even with varying distances of the object from the sensors. Specifically, the measured voltages were approximately 1.2V with no obstacle, 1.4V at 200mm, 1.7V at 150mm, and 2.2V at 100mm for all test points (TP4, TP2, TP6).

These high analog voltages posed a problem for the level shifter, which was designed to work with a threshold of around 0.7V. The potentiometer included on the board was considered as a potential solution for adjusting the voltage levels. However, it was determined that this approach would not be robust enough to account for real-world fluctuations in ambient lighting conditions.

To address this issue, the decision was made to connect the analog outputs directly to the ADC pins of the microcontroller (PA4, PA5, PA6) via pins 7, 11, and 13 on the 2x14 connector. This modification required severing the connections to the level shifter and soldering wires from test points TP2, TP6, and TP7 to pins 7, 11, and 13, respectively.

By utilizing the ADC, it became possible to capture and interpret the analog voltages programmatically, allowing for the implementation of a range of values that the circuit can work with to account for variations in ambient light. This modification meant that AT-02 could no longer be passed in its original form, but it ultimately led to a more adaptable and robust solution for handling the analog output voltages from the ER subsystems.

#### AT-03: Functionality test of the sensing subsystem software
The change in approach from using a level shifter to an ADC necessitated significant modifications to the sensing subsystem software. Initially, the software was designed to receive digital outputs from the level shifter to toggle the LEDs (PB7, PB5, PB6) based on the presence or absence of a wall. However, with the ADC implementation, the software needed to be updated to read the analog values and determine the presence of a wall based on predefined thresholds.

To facilitate the calibration process, an LCD was added to display the ADC values corresponding to the sensor outputs. This allowed for real-time monitoring and adjustment of the threshold values for each ER subsystem (left, right, and front).

During testing, the micro-mouse was set up in a controlled environment, and the LEDs were initially checked for proper functionality. If an LED did not illuminate as expected, the corresponding ADC threshold value was recalibrated. The testing procedure involved iteratively adjusting the threshold values for each ER subsystem, which were read through ADC channels PA4, PA5, and PA6, while monitoring the LED states and the ADC values displayed on the LCD.

This iterative calibration process was continued until the LEDs consistently toggled on and off based on the presence or absence of walls at the defined threshold values. The successful passing of AT-03 after this calibration procedure demonstrates the effectiveness of the revised software design in interpreting the analog sensor data and accurately detecting the presence of walls.

#### AT-04: Power consumption test of the sensing subsystem
During the power consumption test (AT-04), it was discovered that sourcing PWM signals directly from the GPIO pins to control the power to the ER subsystems was not feasible due to current limitations. To overcome this challenge, a P-channel MOSFET was sourced from the White Lab and incorporated into the circuit.

The P-channel MOSFET was configured with its source connected to the 3.7V battery (BATT), and its gate connected to a PWM-capable pin (PE15) of the microcontroller, which corresponds to pin 8 on the 2x14 connector. The drain of the MOSFET was then used as the voltage source for the ER subsystems, with a voltage close to 3.7V.

Initial testing revealed that with all components connected (except for the level shifter), the current drawn by the system was approximately 295mA, close to the expected 300mA (100mA for each of the three ER subsystems). Adjusting the PWM frequency to 1Hz resulted in a noticeable reduction in power consumption while still providing sufficient time for the IR emitters to illuminate and be detected by the sensors. However, it was observed that the analog output voltages at test points TP4, TP2, and TP6 were also affected by the PWM signal.

To mitigate this issue, the decision was made to connect only the IR emitters to the PWM-controlled voltage source (drain of the P-channel MOSFET), while the receivers (photodiodes) were powered directly from the 3.7V battery (BATT). This approach made sense conceptually, as the emitters are the primary current-drawing components, whereas the photodiodes only draw current when receiving reflected IR light.

After implementing this modification, the testing procedure was repeated successfully, and a PWM duty cycle of 50% was selected as it provided an optimal balance between power savings and reliable wall detection, allowing sufficient time for the emitters to illuminate and the sensors to capture the reflected IR light.

#### AT-05: Physical compatibility test
The physical compatibility test (AT-05) focused on ensuring that the sensing subsystem PCB fits within the specified dimensions and connects properly to the motherboard. The length of the PCB was measured to be 54mm, which was deemed optimal for preventing sensor obstruction by the wheels while maintaining a compact overall design.

During testing, the PCB was successfully connected to the motherboard using the appropriate 2x14 2.54mm pin header, and all connections were verified to be secure. The test was passed, confirming that the sensing subsystem PCB meets the physical compatibility requirements for integration with the micro-mouse platform.

# Conclusion

The design and implementation of the sensing subsystem for the micro-mouse project presented numerous challenges and opportunities for learning and improvement. Through a systematic approach to problem-solving, a functional sensing subsystem was developed that met the project's requirements and specifications.

The results of the Acceptance Tests clearly demonstrated the importance of careful component selection, proper power management, and iterative software development in achieving a reliable and efficient sensing subsystem. The initial setbacks encountered during testing, such as incorrect component values and incompatible sensing directions, highlighted the need for thorough research and attention to detail in the design process. By addressing these issues through component replacements and circuit modifications, the sensing subsystem was able to successfully detect walls within the specified range and provide consistent output voltages.

The decision to transition from a level shifter to an ADC for processing the analog sensor data proved to be a turning point in the project. This modification not only simplified the interfacing between the sensing subsystem and the processor but also provided greater flexibility in handling variations in ambient light conditions. The success of this approach was evident in the results of AT-03, which demonstrated the effectiveness of the revised software design in accurately detecting the presence of walls.

Power management emerged as another critical aspect of the sensing subsystem design. The incorporation of a P-channel MOSFET and PWM control, as demonstrated in AT-04, successfully reduced power consumption while maintaining reliable wall detection capabilities. This outcome underscores the significance of careful power analysis and the implementation of efficient power-saving mechanisms in battery-operated systems like the micro-mouse.

The physical compatibility test (AT-05) confirmed that the sensing subsystem PCB met the size and connectivity requirements for integration with the micro-mouse platform. This result highlights the importance of considering mechanical constraints and interfacing requirements early in the design process to ensure seamless integration of subsystems.

In conclusion, the sensing subsystem design project successfully addressed the challenges of wall detection, power efficiency, and system integration. The results obtained from the Acceptance Tests clearly support the effectiveness of the design decisions and modifications made throughout the project. The lessons learned from this experience, such as the importance of component selection, power management, and adaptable software design, will be invaluable in future engineering endeavors.

To further enhance the sensing subsystem and the overall micro-mouse project, several suggestions for future work can be made:

1. Implement a potentiometer to aid in calibrating the ADC. Instead of continuously modifying the code to find the optimal boundary values for the ADC, a potentiometer could be used to adjust either the output of the ER subsystem or the range of the ADC. This would allow for more precise and efficient calibration of the sensing subsystem.

2. Include more jumpers in the PCB design to facilitate circuit separation and debugging. During the project, insufficient jumpers led to the need for manual severing of connections using a screwdriver to cut copper traces. By incorporating more jumpers at strategic locations, future iterations of the PCB design can provide greater flexibility and ease of modification, reducing the need for physical alterations to the board.

3. Investigate the use of shielding techniques to minimize the impact of electromagnetic interference (EMI) on the sensing subsystem. As the micro-mouse operates in close proximity to motors and other electronic components, EMI can potentially affect the performance of the sensors. By implementing appropriate shielding methods, such as grounded enclosures or EMI-suppressing materials, the sensing subsystem can be made more robust and resistant to external noise sources.

4. Develop a comprehensive testing protocol that includes a wider range of environmental conditions and maze configurations. While the Acceptance Tests conducted in this project provided valuable insights into the sensing subsystem's performance, additional testing under varied lighting conditions, surface textures, and maze layouts would help identify potential weaknesses and areas for improvement. This expanded testing approach would contribute to the development of a more reliable and adaptable sensing subsystem.

5. Explore the possibility of integrating multiple types of sensors to enhance the micro-mouse's navigation capabilities. In addition to the current IR emitter-receiver pairs, the use of other sensing technologies, such as ultrasonic or time-of-flight sensors, could provide complementary information about the maze environment. By fusing data from multiple sensor modalities, the micro-mouse could achieve a more comprehensive understanding of its surroundings, enabling more advanced navigation strategies and improved maze-solving performance.

By addressing these suggestions, future iterations of the micro-mouse project can achieve even higher levels of performance, efficiency, and robustness, ultimately leading to a more competitive and successful maze-solving robot. The insights gained from this project, combined with the proposed enhancements, will serve as a solid foundation for further development and optimization of the sensing subsystem and the overall micro-mouse platform.

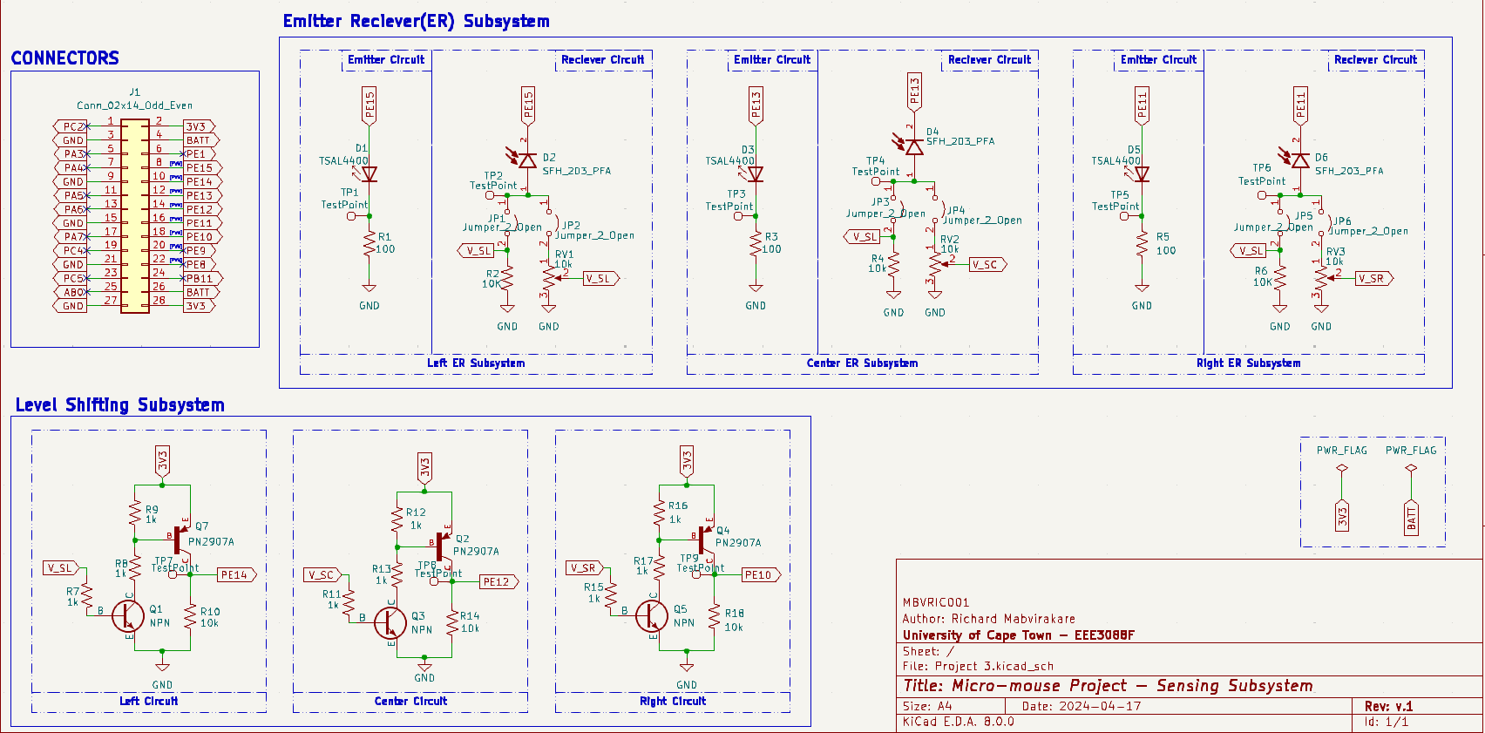
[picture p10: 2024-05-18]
Sensing Subsystem/Figures/schematic.png

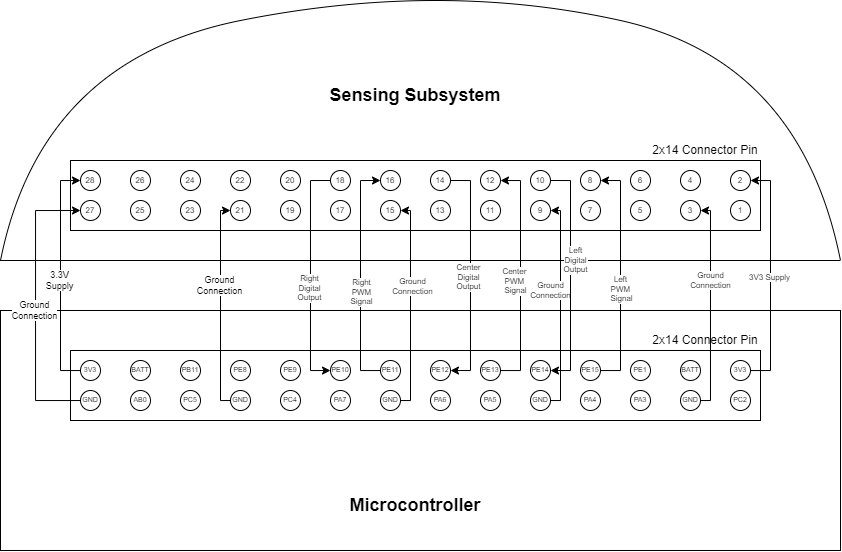
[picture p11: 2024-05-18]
Sensing Subsystem/Figures/High Level diagram.png

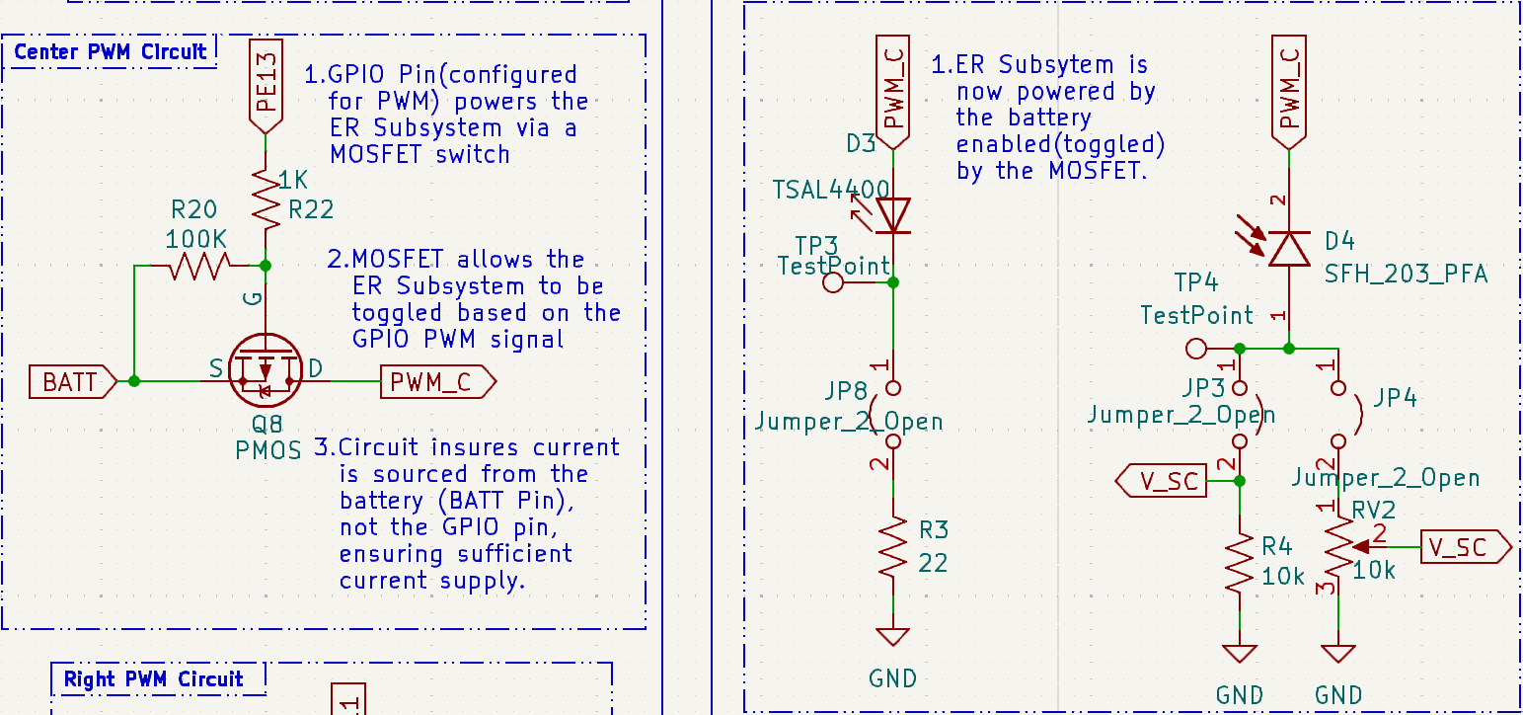
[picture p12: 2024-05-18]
Sensing Subsystem/Figures/PWM - Improved (2).png

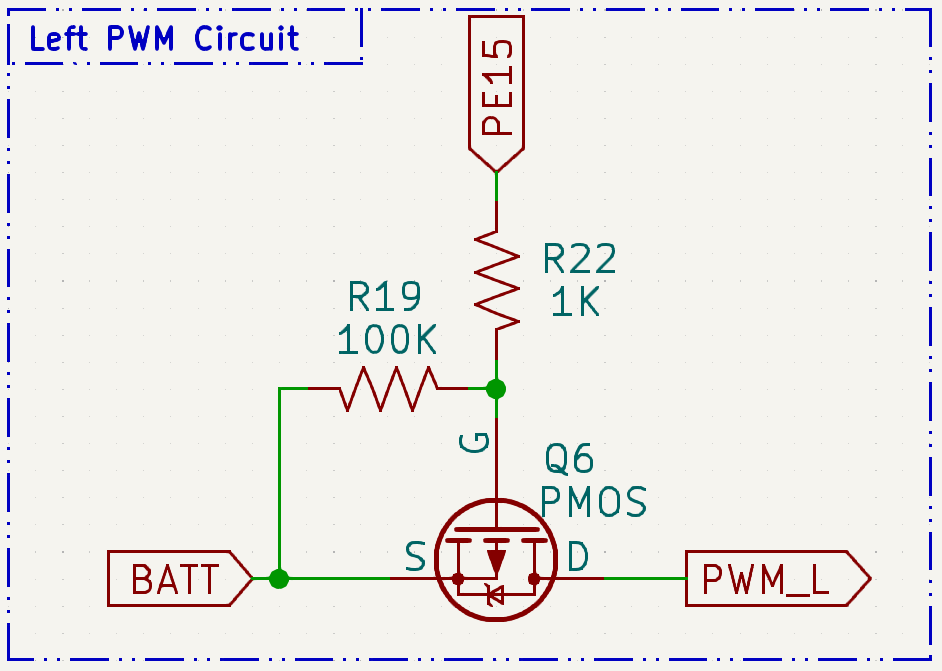
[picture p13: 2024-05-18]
Sensing Subsystem/Figures/MOSFET Switching Circuit.png

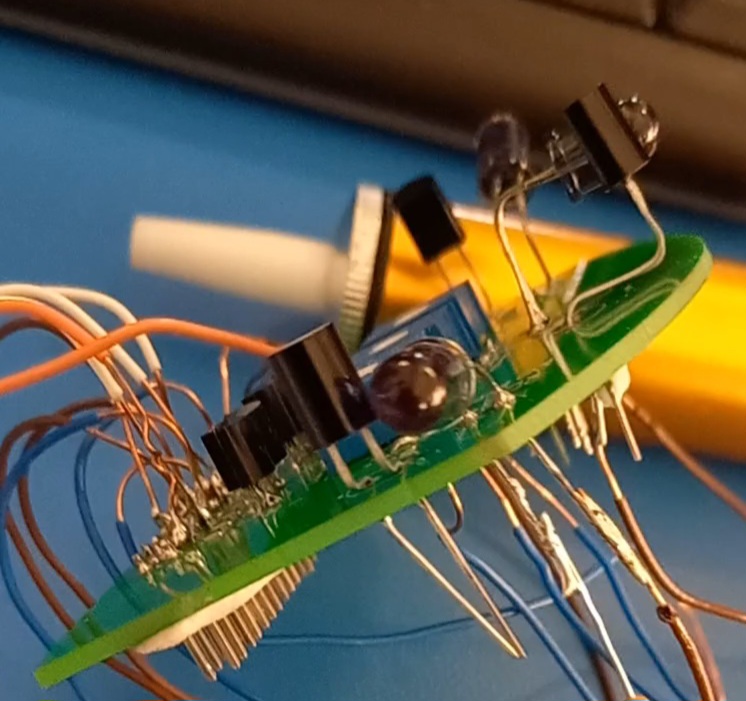
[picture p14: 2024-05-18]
Sensing Subsystem/Figures/evidence/IR not on.jpg

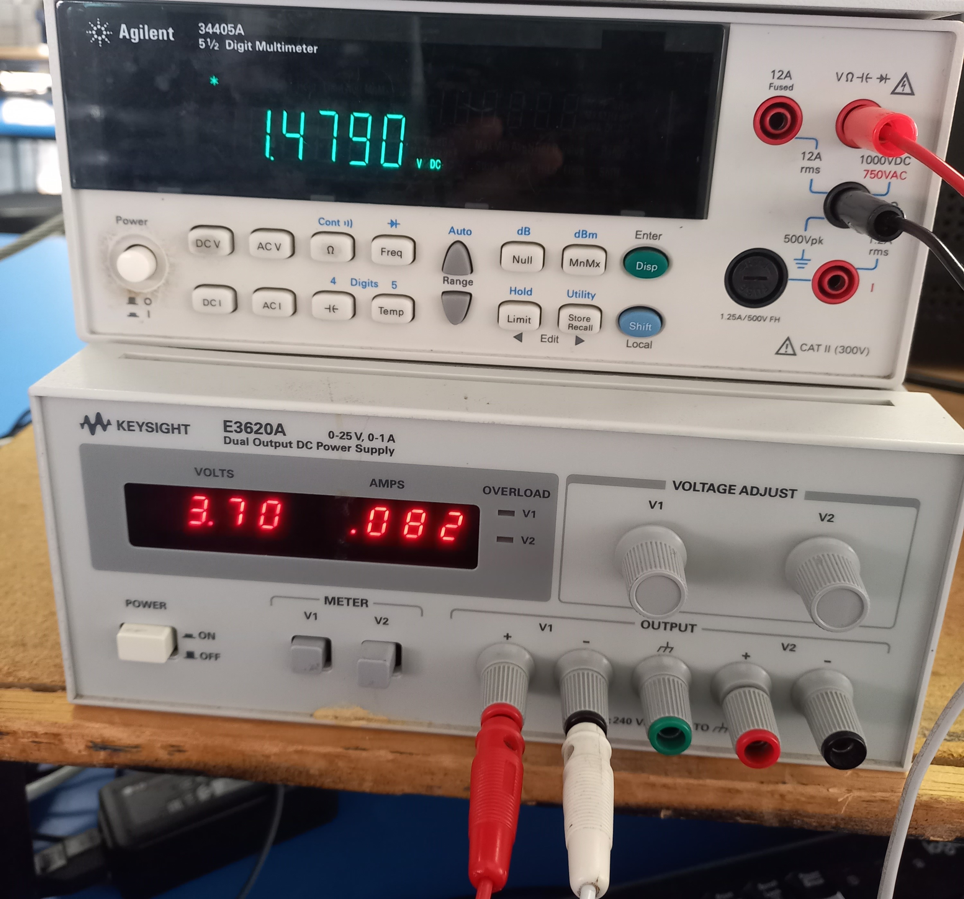
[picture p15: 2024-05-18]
Sensing Subsystem/Figures/evidence/object.jpg

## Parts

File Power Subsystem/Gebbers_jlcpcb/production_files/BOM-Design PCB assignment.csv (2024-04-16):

Comment | Designator | Footprint | LCSC
SW_Push | SW1 | KSA_Tactile_SPST
TestPoint | TP6 | TestPoint_Pad_D1.0mm
Conn_01x02_Pin | J1 | JST_PH_B2B-PH-K_1x02_P2.00mm_Vertical
2k | Rprog1 | R_Axial_DIN0204_L3.6mm_D1.6mm_P5.08mm_Horizontal
TestPoint | TP7 | TestPoint_Pad_D1.0mm
1k | Rled1 | R_Axial_DIN0204_L3.6mm_D1.6mm_P5.08mm_Horizontal
L293D | U1 | DIP-16_W7.62mm
TestPoint | TP3 | TestPoint_Pad_D1.0mm
TestPoint | TP4 | TestPoint_Pad_D1.0mm
TestPoint | TP2 | TestPoint_Pad_D1.0mm
1K8 | R9 | R_Axial_DIN0204_L3.6mm_D1.6mm_P5.08mm_Horizontal
1K | R10 | R_Axial_DIN0204_L3.6mm_D1.6mm_P5.08mm_Horizontal
4.7uF | C2 | CP_Radial_D4.0mm_P2.00mm
Conn_02x08_Counter_Clockwise_MountingPin | J2 | PinSocket_2x07_P2.54mm_Vertical
MCP73831T-2ACI/OT | U2 | SOT-23-5
TestPoint | TP1 | TestPoint_Pad_D1.0mm
4.7uF | C1 | CP_Radial_D4.0mm_P2.00mm
LED | charging1 | LED_D3.0mm

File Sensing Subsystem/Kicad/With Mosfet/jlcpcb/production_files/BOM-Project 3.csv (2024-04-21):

Comment | Designator | Footprint | LCSC
PMOS | Q6,Q8,Q9 | SOT-23-3 | C15127
1k | R11,R12,R13,R15,R16,R17,R7,R8,R9 | R_0603_1608Metric | C23186
10k | R10,R14,R18,R2,R4,R6 | R_0603_1608Metric | C23192
100 | R1,R3,R5 | R_0603_1608Metric | C23345
PN2907A | Q2,Q4,Q7 | TO92-EBC | C358534
NPN | Q1,Q3,Q5 | TO-92L | C5330385
SFH_203_PFA | D2,D4,D6 | XDCR_SFH_203_PFA | C554984
TSAL4400 | D1,D3,D5 | LED_D3.0mm_Horizontal_O1.27mm_Z2.0mm_IRBlack | C94135
10k | RV2 | POT_3386P
10k | RV3 | POT_3386P
10k | RV1 | POT_3386P
Conn_02x14_Odd_Even | J1 | PinHeader_2x14_P2.54mm_Vertical

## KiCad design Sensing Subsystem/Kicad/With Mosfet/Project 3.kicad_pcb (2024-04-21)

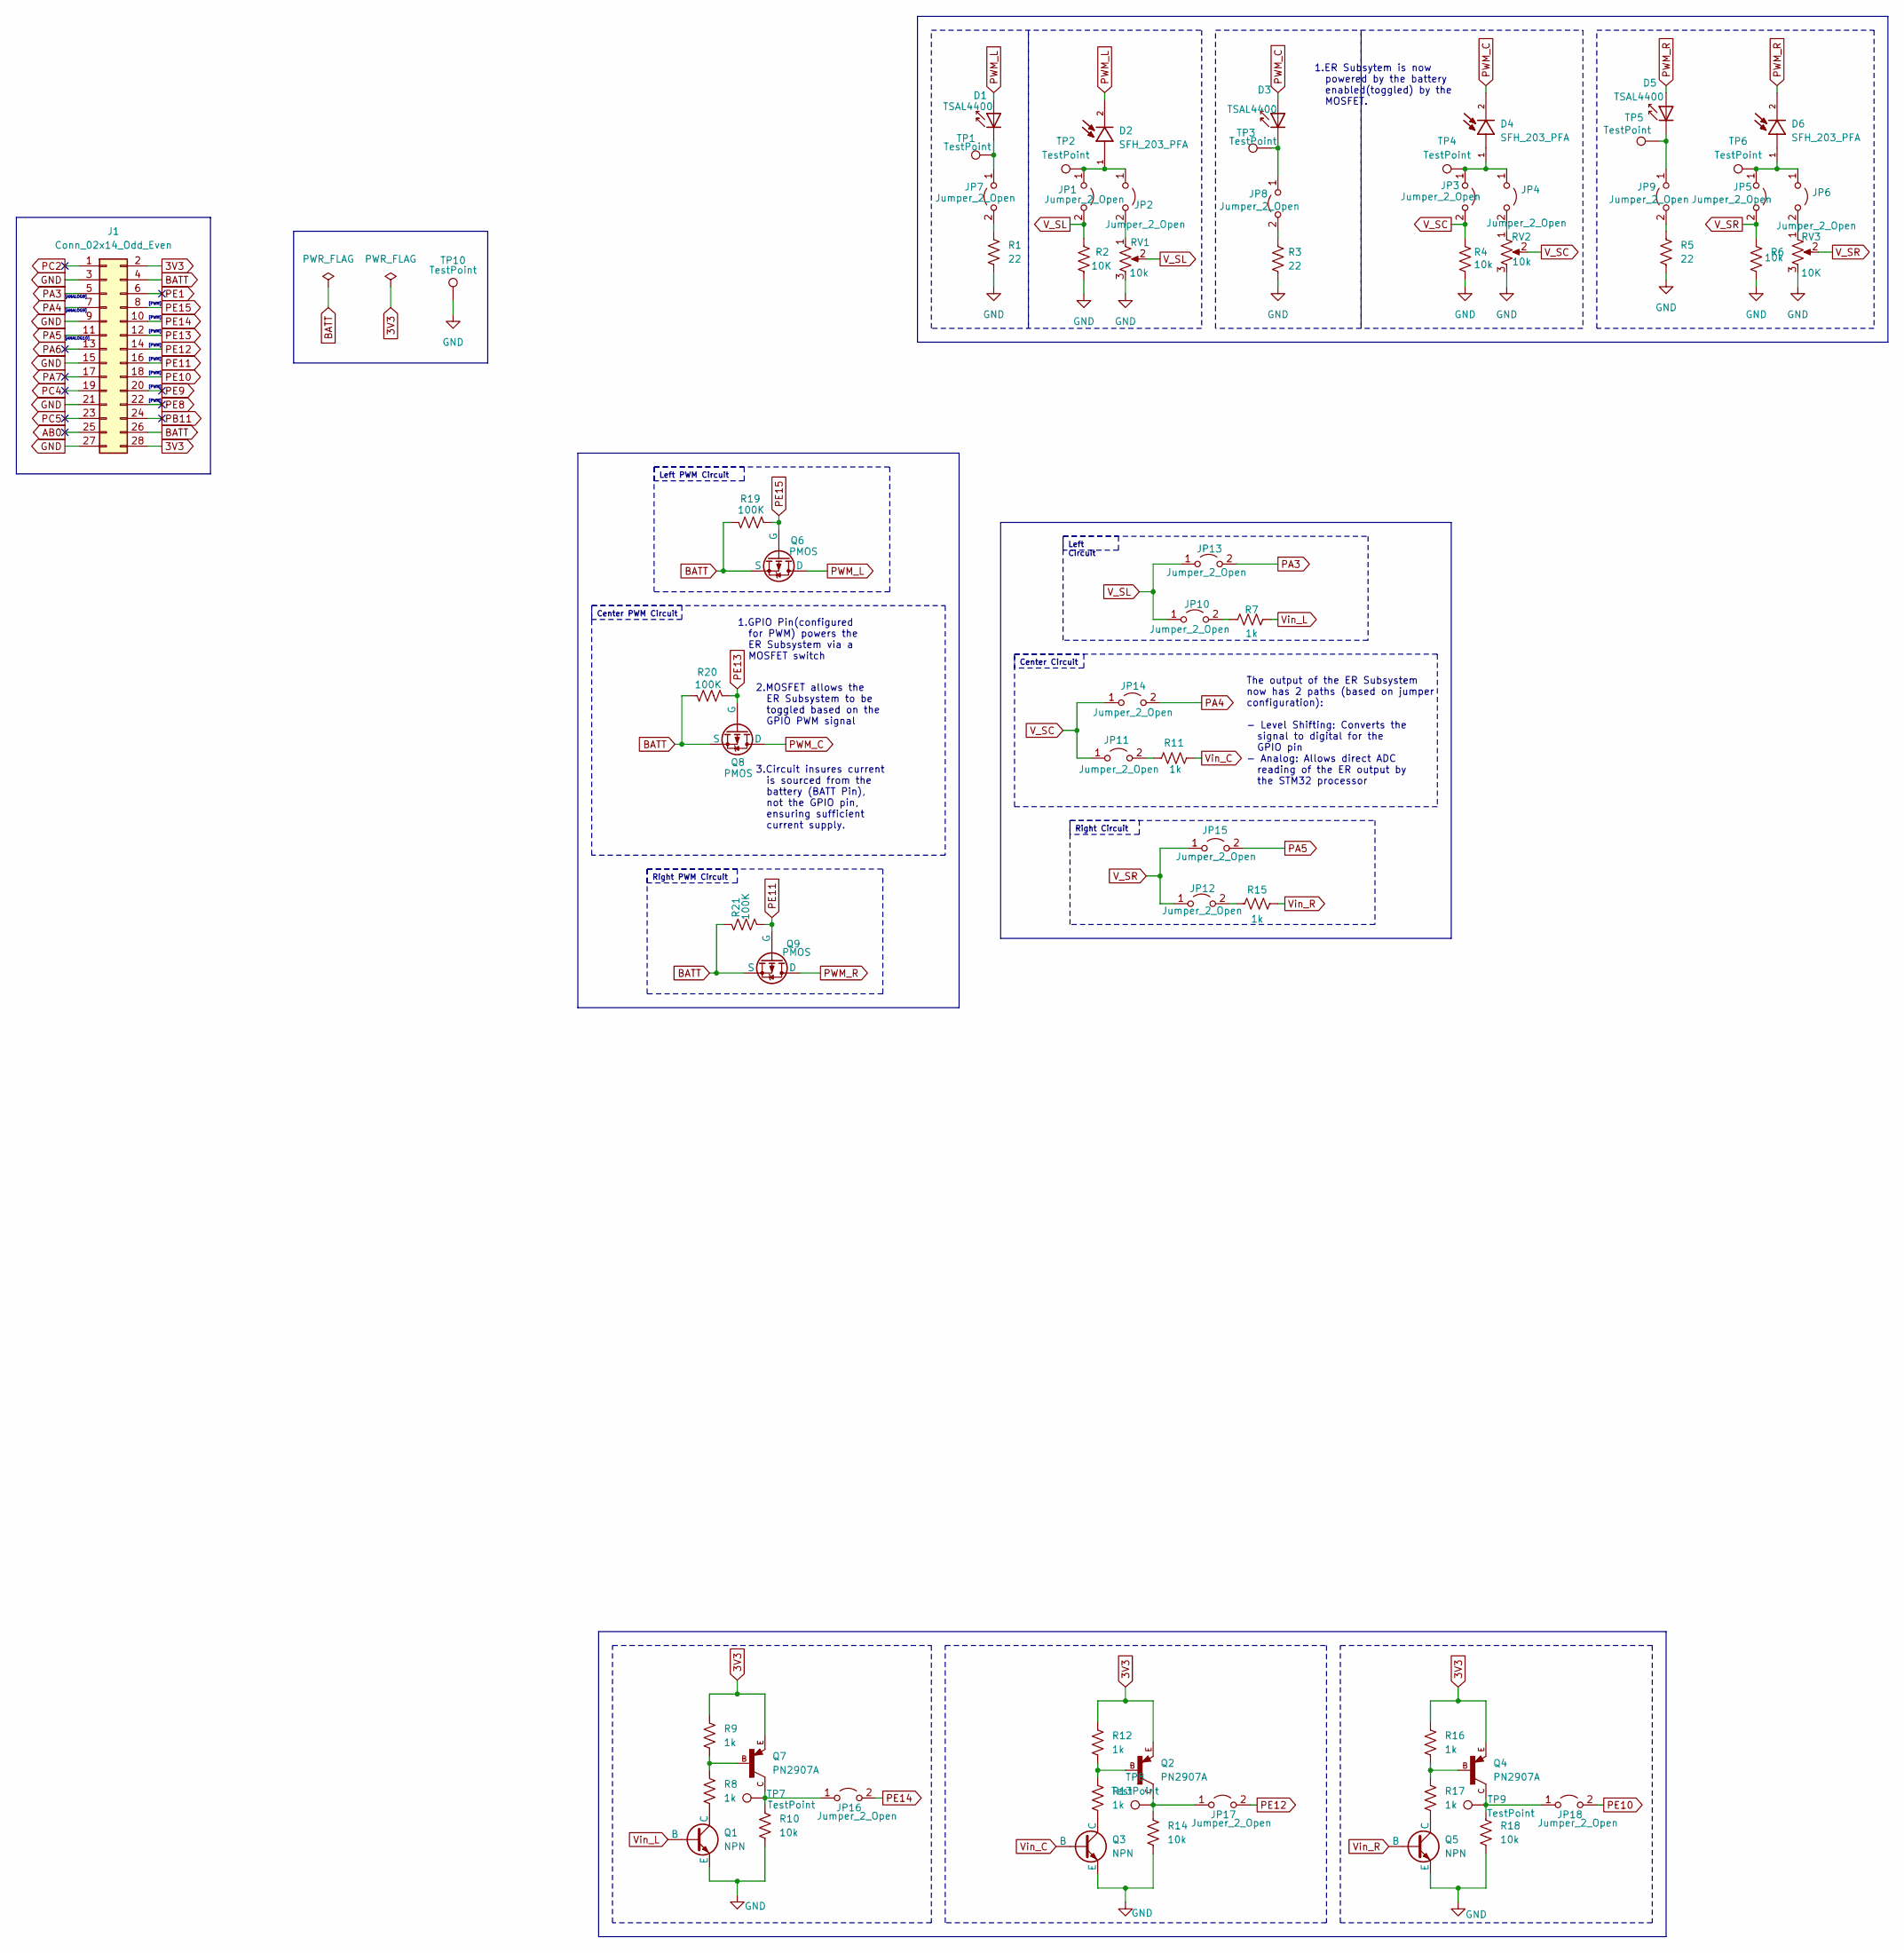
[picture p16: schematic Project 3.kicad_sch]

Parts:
D1, D3, D5: TSAL4400; LED_D3.0mm_Horizontal_O1.27mm_Z2.0mm_IRBlack
D2, D4, D6: SFH_203_PFA; XDCR_SFH_203_PFA; PARTREV 1.3
J1: Conn_02x14_Odd_Even; PinHeader_2x14_P2.54mm_Vertical
JP1, JP2, JP3, JP4, JP5, JP6, JP7, JP8, JP9, JP10, JP11, JP12, JP13, JP14, JP15, JP16, JP17, JP18: Jumper_2_Open; SolderJumper-2_P1.3mm_Open_Pad1.0x1.5mm
Q1, Q3, Q5: NPN; TO-92L
Q2, Q4, Q7: PN2907A; TO92-EBC
Q6, Q8, Q9: PMOS; SOT-23-3
R1, R3, R5: 22; R_0603_1608Metric
R2, R6: 10K; R_0603_1608Metric
R4, R10, R14, R18: 10k; R_0603_1608Metric
R7, R8, R9, R11, R12, R13, R15, R16, R17: 1k; R_0603_1608Metric
R19, R20, R21: 100K; R_0603_1608Metric
RV1, RV2, RV3: 10k; POT_3386P
TP1, TP2, TP3, TP4, TP5, TP6, TP7, TP8, TP9, TP10: TestPoint; TestPoint_Pad_D1.0mm

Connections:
3V3: J1.2, J1.28, Q2.E, Q4.E, Q7.E, R9.2, R12.2, R16.2
AB0: J1.25
BATT: J1.4, J1.26, Q6.3 (S), Q8.3 (S), Q9.3 (S), R19.2, R20.2, R21.2
GND: J1.3, J1.9, J1.15, J1.21, J1.27, Q1.3 (E), Q3.3 (E), Q5.3 (E), R1.1, R2.1, R3.1, R4.1, R5.1, R6.1, R10.1, R14.1, R18.1, RV1.3, RV2.3, RV3.3, TP10.1
unnamed: D1.2 (A), D2.2, Q6.1 (D)
unnamed: D1.1 (K), JP7.1 (A), TP1.1
unnamed: D3.2 (A), D4.2, Q8.1 (D)
unnamed: D3.1 (K), JP8.1 (A), TP3.1
unnamed: D5.2 (A), D6.2, Q9.1 (D)
unnamed: D2.1, JP1.1 (A), JP2.1 (A), TP2.1
unnamed: JP2.2 (B), RV1.1
unnamed: D4.1, JP3.1 (A), JP4.1 (A), TP4.1
unnamed: JP4.2 (B), RV2.1
unnamed: D6.1, JP5.1 (A), JP6.1 (A), TP6.1
unnamed: JP6.2 (B), RV3.1
unnamed: JP7.2 (B), R1.2
unnamed: JP8.2 (B), R3.2
unnamed: JP10.2 (B), R7.1
unnamed: JP11.2 (B), R11.1
unnamed: JP12.2 (B), R15.1
unnamed: JP16.1 (A), Q7.C, R10.2, TP7.1
unnamed: JP17.1 (A), Q2.C, R14.2, TP8.1
unnamed: JP18.1 (A), Q4.C, R18.2, TP9.1
unnamed: Q1.2 (B), R7.2
unnamed: Q1.1 (C), R8.1
unnamed: Q2.B, R12.1, R13.2
unnamed: Q3.2 (B), R11.2
unnamed: Q3.1 (C), R13.1
unnamed: Q4.B, R16.1, R17.2
unnamed: Q5.2 (B), R15.2
unnamed: Q5.1 (C), R17.1
unnamed: Q7.B, R8.2, R9.1
PA3: J1.5, JP13.2 (B)
PA4: J1.7, JP14.2 (B)
PA5: J1.11, JP15.2 (B)
PA6: J1.13
PA7: J1.17
PB11: J1.24
PC2: J1.1
PC4: J1.19
PC5: J1.23
PE1: J1.6
PE8: J1.22
PE9: J1.20
PE10: J1.18, JP18.2 (B)
PE11: J1.16, Q9.2 (G), R21.1
PE12: J1.14, JP17.2 (B)
PE13: J1.12, Q8.2 (G), R20.1
PE14: J1.10, JP16.2 (B)
PE15: J1.8, Q6.2 (G), R19.1
V_SC: JP3.2 (B), JP11.1 (A), JP14.1 (A), R4.2, RV2.2
V_SL: JP1.2 (B), JP10.1 (A), JP13.1 (A), R2.2, RV1.2
V_SR: JP5.2 (B), JP12.1 (A), JP15.1 (A), R6.2, RV3.2

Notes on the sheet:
Right PWM Circuit
Center PWM Circuit
Left PWM Circuit
Left Circuit
Center Circuit
Right Circuit
The output of the ER Subsystem now has 2 paths (based on jumper configuration): - Level Shifting: Converts the signal to digital for the GPIO pin - Analog: Allows direct ADC reading of the ER output by the STM32 processor
1.ER Subsytem is now powered by the battery enabled(toggled) by the MOSFET.
[PWM]
[ANALOG9]
3.Circuit insures current is sourced from the battery (BATT Pin), not the GPIO pin, ensuring sufficient current supply.
[ANALOG10]
1.GPIO Pin(configured for PWM) powers the ER Subsystem via a MOSFET switch
[ANALOG8]
2.MOSFET allows the ER Subsystem to be toggled based on the GPIO PWM signal

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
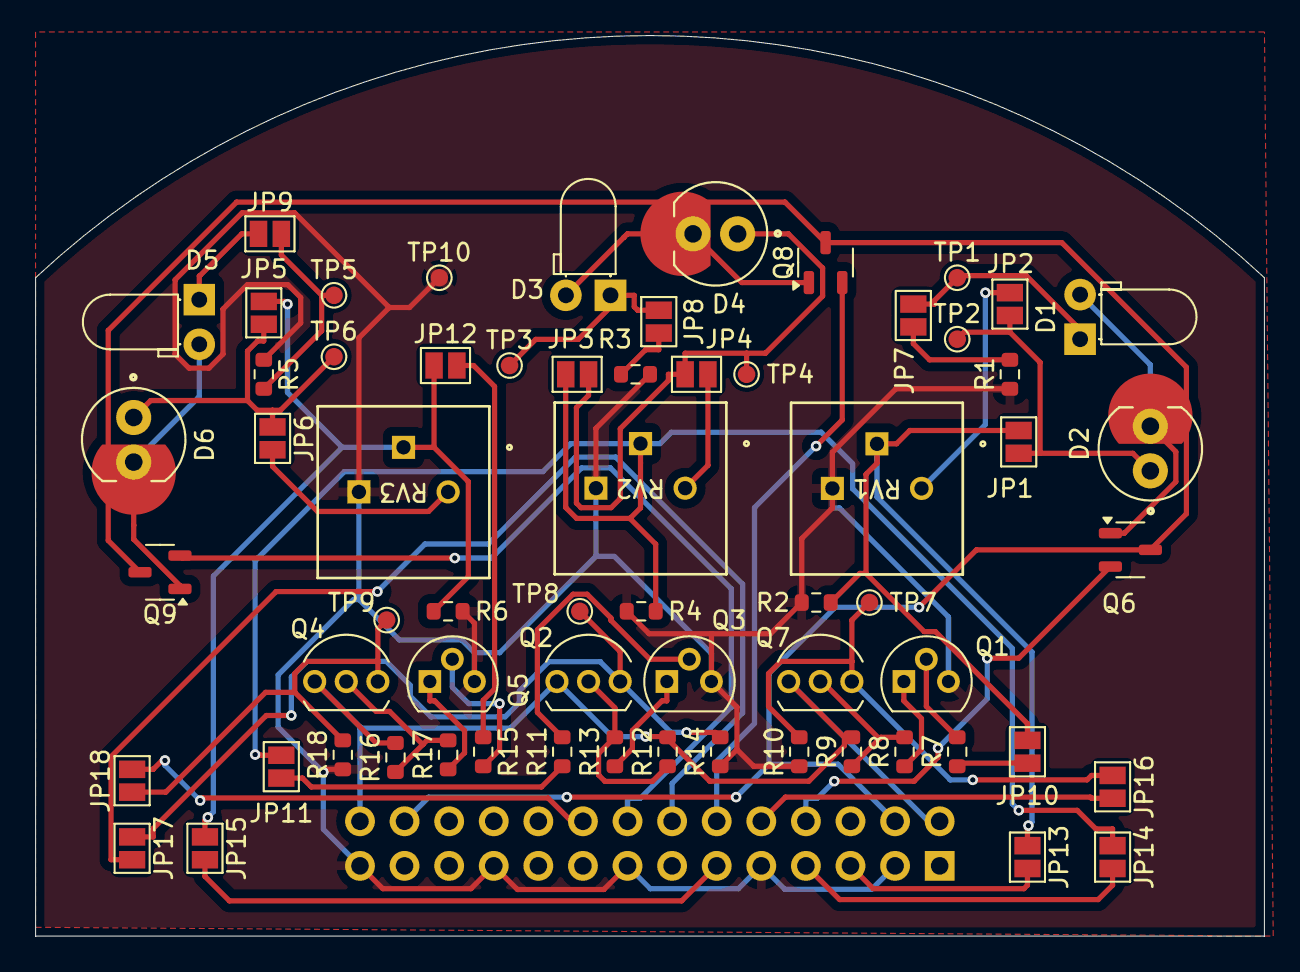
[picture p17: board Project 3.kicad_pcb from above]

Board: 2 copper layers, 70.0 x 51.3 mm, 65 parts (1 on the bottom side), 45 nets.

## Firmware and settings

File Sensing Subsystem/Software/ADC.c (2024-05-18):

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
/* Includes ------------------------------------------------------------------*/
#include "main.h"

/* USER CODE BEGIN Includes */
#include "string.h"
#include "stm32f0xx_hal.h"
#include <stdio.h>
#include "lcd_stm32f0.h"
/* USER CODE END Includes */

ADC_HandleTypeDef hadc;

/* USER CODE BEGIN PV */
uint16_t adc_value_front_sensor;
uint16_t adc_value_right_sensor;
uint16_t adc_value_left_sensor;
uint16_t adc_value;
uint8_t channel = 1;


char str_adc_value_front[100];
char str_adc_value_right[100];
char str_adc_value_left[100];



/* USER CODE END PV */

void SystemClock_Config(void);
static void MX_GPIO_Init(void);
static void MX_ADC_Init(void);
/* USER CODE BEGIN PFP */
uint16_t read_adc();
void adc_set_channel(uint8_t num);

/* USER CODE END PFP */

/**
  * @brief  The application entry point.
  * @retval int
  */
int main(void)
{
  /* MCU Configuration--------------------------------------------------------*/

  /* Reset of all peripherals, Initializes the Flash interface and the Systick. */
  HAL_Init();

  /* Configure the system clock */
  SystemClock_Config();

  /* Initialize all configured peripherals */
  MX_GPIO_Init();
  MX_ADC_Init();
  /* USER CODE BEGIN 2 */
  lcd_init(); // set up LCD lines and send initialisation commands
  lcd_command(LCD_CLEAR_DISPLAY);
  //lcd_command(LCD_GOTO_LINE_2);


  /* USER CODE END 2 */

  /* Infinite loop */
  /* USER CODE BEGIN WHILE */
  while (1)
  {
    /* USER CODE END WHILE */
	      ADC1->CHSELR = ADC_CHSELR_CHSEL1;
	      HAL_Delay(1);
		 // adc_set_channel(channel);
		  adc_value_front_sensor = read_adc() ;
		 HAL_ADC_Stop(&hadc);

			 if(adc_value_front_sensor > 15) {
				 HAL_GPIO_WritePin(GPIOB, GPIO_PIN_6, GPIO_PIN_SET);
			  }
			 else if (adc_value_front_sensor < 5){
			 HAL_GPIO_WritePin(GPIOB, GPIO_PIN_6, GPIO_PIN_RESET);

		  }


		  ADC1->CHSELR = ADC_CHSELR_CHSEL2;
		  HAL_Delay(1);
		 // adc_set_channel(channel);
		  adc_value_right_sensor = read_adc() ;
		  HAL_ADC_Stop(&hadc);

		 if(adc_value_right_sensor > 370) {
		 		HAL_GPIO_WritePin(GPIOB, GPIO_PIN_5, GPIO_PIN_SET);
		 		  }
		 else if (adc_value_right_sensor < 350){
		 		 HAL_GPIO_WritePin(GPIOB, GPIO_PIN_5, GPIO_PIN_RESET);
		 		  }

		 ADC1->CHSELR = ADC_CHSELR_CHSEL3;
		 HAL_Delay(1);
		// adc_set_channel(channel);
		 adc_value_left_sensor = read_adc() ;
		 HAL_ADC_Stop(&hadc);

		 if(adc_value_left_sensor > 430) {
		 	HAL_GPIO_WritePin(GPIOB, GPIO_PIN_7, GPIO_PIN_SET);
		 		  }
		 else if (adc_value_left_sensor < 410){
		 	 HAL_GPIO_WritePin(GPIOB, GPIO_PIN_7, GPIO_PIN_RESET);
		 		  }


		//  HAL_Delay(500);



		  HAL_Delay(1000);

	  channel++;
	  sprintf(str_adc_value_front, "F_S_ADC = %d", adc_value_front_sensor);
	  sprintf(str_adc_value_right, "R_S_ADC = %d", adc_value_right_sensor);
	  sprintf(str_adc_value_left, "L_S_ADC = %d", adc_value_left_sensor);

	  lcd_command(LCD_GOTO_LINE_2);

	  lcd_two_line_write(str_adc_value_front, str_adc_value_right );
	  HAL_Delay(1000);
	  lcd_command(LCD_CLEAR_DISPLAY);
	  lcd_command(LCD_GOTO_LINE_2);
	  lcd_string(str_adc_value_left);
	 HAL_Delay(100);

	  lcd_command(LCD_CLEAR_DISPLAY);
	  /* USER CODE END WHILE */




    /* USER CODE BEGIN 3 */
  }
  /* USER CODE END 3 */
}

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
/* USER CODE BEGIN 4 */
uint16_t read_adc()
{

	    HAL_ADC_Start(&hadc);
	    while(HAL_ADC_PollForConversion(&hadc,5)!= HAL_OK);
	    adc_value = HAL_ADC_GetValue(&hadc);
	    return adc_value;

}
void adc_set_channel(uint8_t num) {
    ADC_ChannelConfTypeDef sConfig = {0};

    if (num==1) {
      sConfig.Channel = ADC_CHANNEL_1;
    } else if (num==2){
      sConfig.Channel = ADC_CHANNEL_2;
    }
    else
    {
    	sConfig.Channel = ADC_CHANNEL_3;
    	channel = 0;
    }
    sConfig.Rank = ADC_RANK_CHANNEL_NUMBER;
    sConfig.SamplingTime = ADC_SAMPLETIME_1CYCLE_5;
    if (HAL_ADC_ConfigChannel(&hadc, &sConfig) != HAL_OK)
    {
      Error_Handler();
    }
}
/* USER CODE END 4 */
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


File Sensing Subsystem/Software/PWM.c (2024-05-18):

#include "stm32f0xx.h"

void GPIO_init(void);
void TimerConfig(void);
void Delay_ms(uint32_t delayTime_ms);
void Delay_us(uint32_t delayTime_us);

int count;
int counter;

int main(){
	GPIO_init();
	TimerConfig();
	while(1){
//PWM for PE15
		GPIOB->ODR ^= GPIO_ODR_15;
		Delay_ms(500);
	}
}

void GPIO_init(void){
	RCC->AHBENR |= RCC_AHBENR_GPIOEEN;
	GPIOB->MODER |= GPIO_MODER_MODER0_0;
}

void TimerConfig(void){
	RCC->APB1ENR |= RCC_APB1ENR_TIM2EN;

	TIM2->PSC = 8-1;
	TIM2->ARR = 0xFFFF-1;

	TIM2->CR1 |= TIM_CR1_CEN;

	while(!(TIM2->SR & TIM_SR_UIF)); //wait for the timer flag to update
}
void Delay_us(uint32_t delayTime_us){
	TIM2->CNT = 0;
	while(TIM2->CNT <delayTime_us);
	count++;
}
void Delay_ms(uint32_t delayTime_ms){
	for(int i = 0;i<delayTime_ms;i++){
		Delay_us(1000);
	}
	counter++;
}

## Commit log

2024-04-16 Power subsystem files
    [BOM-Design PCB assignment.csv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]
2024-04-21 Richards Folder
    [BOM-Project 3.csv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]
2024-04-21 Datasheets for other drivers and charging ICs
2024-05-18 Add ADC and PWM code

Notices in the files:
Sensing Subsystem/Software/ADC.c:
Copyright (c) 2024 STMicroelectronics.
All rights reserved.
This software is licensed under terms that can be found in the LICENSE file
